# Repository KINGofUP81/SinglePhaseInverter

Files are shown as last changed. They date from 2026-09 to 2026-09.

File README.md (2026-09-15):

# Single-Phase H-Bridge Inverter

A **380 V DC → single-phase AC** full-bridge inverter power board designed in Altium Designer. It combines a 650 V MOSFET H-bridge, bootstrap gate drive, an LC output filter and a complete sensing suite (DC bus voltage and current, AC output voltage and current, heatsink temperature). Everything is broken out to header connectors for an external STM32 controller.

> Designed at **IIT Ropar** by **Afraaz Khan**, **Zeeshan** and **Kratika**, under the guidance of **Prof. Saifullah Payami**.

---

## Highlights

| | |
|---|---|
| ⚡ **DC bus** | 380 V input, 2 × 470 µF / 450 V bulk capacitors with bleeder resistors, film decoupling and snubbers |
| 🔀 **Power stage** | Full H-bridge of 4 × **STW69N65M5** 650 V MDmesh™ M5 MOSFETs (TO-247) on heatsinks |
| 🎛️ **Gate drive** | 2 × **IR2110** high/low-side drivers with MUR160G bootstrap diodes |
| 🌊 **Output filter** | 2.2 mH inductor + 3 × 2.2 µF film capacitors for a clean sinusoidal output |
| 📏 **Sensing** | DC current (ACS758), AC current (ZMCT103C CT), DC bus and AC output voltage dividers, LM35 temperature |
| 🛡️ **Protection** | MOV, TVS, Zener gate clamps, Schottky ADC clamps, shutdown/fault line |
| 🧱 **PCB** | 4-layer stack-up with separate power and signal grounds |

## System Overview

```
                  ┌───────────────────── H-bridge ─────────────────────┐
 +380 V DC ──┬──► │  Q1 ─┐                                   ┌─ Q2      │
             │    │      ├── NODE_A ──► L1 2.2 mH ──► C 3×2.2µF ──┼──► AC_LINE
  C5/C6 470µF│    │  Q3 ─┘                                   └─ Q4      │──► AC_NEUTRAL
             │    └──────▲────────────────────────────────────▲────────┘
            PGND     IR2110 (A)                           IR2110 (B)
                          ▲                                    ▲
                    HIN_A / LIN_A                        HIN_B / LIN_B
                          └──────────── STM32 controller ──────┘
                                           ▲
       VBUS_FB · CURRENT_FB · VOUT_FB · COUT_FB · TEMP_FB · SD_FAULT
```

An external STM32 generates sinusoidal PWM (e.g. SPWM) for the two legs. The IR2110s level-shift that PWM to drive the four MOSFETs, the LC filter recovers the fundamental, and the feedback signals close the voltage and current loops.

## Bill of Materials (key parts)

| Block | Part | Qty | Role |
|---|---|---|---|
| Power switches | STMicro **STW69N65M5** | 4 | 650 V N-channel MOSFETs, H-bridge |
| Gate drivers | Infineon **IR2110** | 2 | High- and low-side driver per leg |
| Bootstrap | MUR160G + 1 µF | 2 | Floating high-side supply |
| Gate network | 22 Ω, 1N4148W, BZT52C18, 1 kΩ | 4 each | Turn-on/off shaping, 18 V clamp, pull-down |
| DC link | ELG477M450AT6AA 470 µF / 450 V | 2 | Bulk bus capacitance |
| DC link | ECW-FE2J105QD 1 µF / 630 V film, ECW-FD2J333JB 33 nF film | 1 + 3 | High-frequency decoupling |
| Output filter | RLB0914-222KL 2.2 mH | 1 | Filter inductor |
| Output filter | ECW-FE2W225KA 2.2 µF film | 3 | Filter capacitors |
| DC current | Allegro **ACS758LCB-050B** | 1 | ±50 A isolated Hall-effect sensor |
| AC current | **ZMCT103C** + 49.9 Ω burden | 1 | Output current transformer |
| Voltage sense | PTF65 1 MΩ precision resistors | 7 | High-voltage dividers |
| Temperature | **LM35DZ** | 1 | Heatsink / board temperature |
| Regulator | LM7805 | 1 | 12 V → 5 V for sensors |
| Protection | B72220S0421K101 MOV, SMAJ15A TVS, BAT54C | 1 each | Surge, rail and ADC-input clamping |
| Noise | BLM21PG221SN1D ferrite bead | 1 | Couples power ground to signal ground |
| Connectors | KF301-2P screw terminals, Harwin M20 headers | 3 + 3 | Power I/O and controller interface |
| Thermal | Wakefield 694-50 heatsinks | 4 | MOSFET cooling |

The full BOM is in [`Singlephaseinverter/SinglephaseinverterBOM.xlsx`](Singlephaseinverter/SinglephaseinverterBOM.xlsx).

## Design Details

<details>
<summary><b>H-bridge & gate drive</b></summary>

Each leg (NODE_A, NODE_B) uses a high-side and a low-side STW69N65M5. With 650 V ratings they give comfortable margin on a 380 V bus, and their low R<sub>DS(on)</sub> keeps conduction loss down.

Each MOSFET gate has:
- a **22 Ω** series resistor to control dv/dt and damp ringing,
- a **1N4148W** diode across it for fast turn-off,
- an **18 V Zener** (BZT52C18) to clamp gate-source spikes,
- a **1 kΩ** gate-source pull-down that holds the device off while the driver is unpowered.

The IR2110s run from a 12 V rail. Their high-side outputs are powered by MUR160G ultrafast bootstrap diodes and local 1 µF capacitors, recharged whenever the low-side switch conducts. The shutdown inputs are tied to a filtered `SD_FAULT` line so the controller can disable all four gates at once.
</details>

<details>
<summary><b>DC link</b></summary>

Two 470 µF / 450 V electrolytics provide bulk energy storage, with a string of 1 MΩ resistors to bleed the bus down safely after power-off. A 1 µF / 630 V film capacitor and three 33 nF film capacitors sit close to the bridge to supply the high-frequency switching current that electrolytics can't.
</details>

<details>
<summary><b>Output LC filter</b></summary>

The switched bridge voltage passes through a 2.2 mH inductor into three parallel 2.2 µF film capacitors (6.6 µF total). This low-pass filter removes the PWM carrier and its harmonics, leaving the fundamental at `AC_LINE` / `AC_NEUTRAL`.
</details>

<details>
<summary><b>Sensing & feedback</b></summary>

| Signal | Sensor | Conditioning |
|---|---|---|
| `VBUS_FB` | 1 MΩ precision divider | Scales the 380 V bus into the ADC range |
| `CURRENT_FB` | ACS758LCB-050B | Isolated Hall-effect DC-link current, ±50 A |
| `VOUT_FB` | 1 MΩ precision divider | AC output voltage, biased with a 10 kΩ network |
| `COUT_FB` | ZMCT103C CT | 49.9 Ω burden, 10 kΩ / 10 kΩ mid-rail bias |
| `TEMP_FB` | LM35DZ | 10 mV/°C analog output |

A BAT54C dual Schottky provides input clamping to protect the MCU's ADC pins, and small filter capacitors on the feedback paths reduce switching noise.
</details>

<details>
<summary><b>Protection</b></summary>

- **MOV** (420 V<sub>RMS</sub>) absorbs surge energy.
- **SMAJ15A TVS** protects the 12 V auxiliary rail.
- **Zener gate clamps** protect each MOSFET gate.
- **Schottky clamps** protect the ADC inputs.
- **`SD_FAULT`** gives the controller a hardware path to shut down all four gates.
</details>

<details>
<summary><b>PCB layout</b></summary>

4-layer FR-4 stack-up:

| Layer | Name | Use |
|---|---|---|
| L1 | `POWER` | High-current bus and bridge routing |
| L2 | `PGND` | Power ground plane |
| L3 | `LOW_POWER` | Gate drive and auxiliary supplies |
| L4 | `SIGNAL/SGND` | Sensing, controller interface, signal ground |

- **Zoning:** the high-voltage section (bus capacitors, bridge, heatsinks, output filter) is kept physically apart from the low-voltage sensing and controller interface.
- **Grounds:** the power and signal grounds are separate, joined through a ferrite bead.
- **Iterations:** the design went through several layout revisions (`PCB1` → `PCB2 (ITERATION)` → `PCBFINAL`), with DRC reports and Gerber/ODB++ outputs generated for each.
</details>

## Controller Interface

| Header | Pins | Signals |
|---|---|---|
| **P1** (4-pin) | 1–4 | `HIN_A`, `LIN_A`, `HIN_B`, `LIN_B` (PWM inputs) |
| **P5** (2-pin) | 1–2 | `CURRENT_FB`, `VBUS_FB` |
| **P6** (6-pin) | 1–6 | `SD_FAULT`, `TEMP_FB`, `SGND`, `COUT_FB`, `VOUT_FB`, `3.3V` |

| Terminal | Connection |
|---|---|
| **P3** | +380 V DC bus input / PGND |
| **P2** | AC output (`AC_LINE` / `AC_NEUTRAL`) |
| **P4** | +12 V auxiliary supply / PGND |

## Repository Contents

```
Singlephaseinverter/
├── Singlephaseinverter.PrjPcb        # Altium project (open this)
├── Sheet2.SchDoc                     # Main schematic
├── PCBFINAL.PcbDoc                   # Final PCB layout
├── PCB1.PcbDoc, PCB2(ITERATION).PcbDoc  # Earlier layout iterations
├── Schlib2.SchLib, PcbLib2.PcbLib    # Project libraries
├── <part folders>/                   # Vendor symbols & footprints (SchLib/PcbLib)
├── *.stp / *.step                    # 3D models
├── SinglephaseinverterBOM.xlsx       # Bill of materials
├── Inverter(FINAL SCHEM).pdf         # Schematic + PCB prints
├── Singlephaseinverter(*).pdf        # Review / submission prints
└── Project Outputs for Singlephaseinverter/
    ├── PCBFINAL.G*                   # Gerbers + drill
    ├── odb/                          # ODB++ fabrication data
    └── Design Rule Check - *.html    # DRC reports
```

📄 **Start here:** [`Inverter(FINAL SCHEM).pdf`](Singlephaseinverter/Inverter(FINAL%20SCHEM).pdf) has the full schematic and PCB layout without needing Altium.

## Getting Started

1. Open `Singlephaseinverter/Singlephaseinverter.PrjPcb` in **Altium Designer**.
2. Review `PCBFINAL.PcbDoc` and re-run DRC.
3. Fabrication files (Gerber, drill, ODB++) are in `Project Outputs for Singlephaseinverter/`.

> ⚠️ **High voltage.** This board runs from a 380 V DC bus and its bulk capacitors store lethal energy. Bring it up with an isolated, current-limited supply, confirm the bus has bled down before touching it, and always use proper isolation and PPE.

## Roadmap

- [ ] Assemble and bring up the power stage
- [ ] Closed-loop SPWM control on STM32 (voltage and current loops)
- [ ] Dead-time and switching-loss optimisation
- [ ] THD measurement of the filtered output
- [ ] Thermal characterisation under load

## Team

| Name | Role |
|---|---|
| **Afraaz Khan** | Hardware design |
| **Zeeshan** | Hardware design |
| **Kratika** | Hardware design |
| **Prof. Saifullah Payami** | Faculty guide, IIT Ropar |

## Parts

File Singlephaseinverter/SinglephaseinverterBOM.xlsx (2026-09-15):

Name | Description | Designator | Footprint | LibRef | Quantity
22u | EEU-FR1H220 | C1, C7 | 22uF | 22u | 2
1uF(New) | CL21B105MBFNNNE | C2, C9 | 1uF(New) | 1uF(New) | 2
1uF | C1206C105K1RACTU | C3, C8, C18 | 1uF | 1uF | 3
1uF Film | ECW-FE2J105QD | C4 | 1.0uF/630V | 1uF Film | 1
470uF/450V | ELG477M450AT6AA | C5, C6 | 470 µF/450 V | 470uF/450V | 2
33nF | ECW-FD2J333JB | C10, C11, C12 | 33nF | 33nF | 3
1nF | C315C102KAG5TA | C13, C14, C20 | 1nF | 1nF | 3
2.2uF | ECWFE2W225KA | C15, C16, C17 | 2.2uF | 2.2uF | 3
100nF/100V | C1210C104K1RACAUTO | C19, C21, C22, R28 | 100nF/100V | 100nF/100V | 4
Rectifier | MUR160G | D1, D2 | Rectifier | Rectifier | 2
Fast Switching Diode | 1N4148W-7-F | D3, D6, D9, D10 | Fast Switching Diode | Fast Switching Diode | 4
Zener Diode | BZT52C18 | D4, D5, D7, D8 | Zener Diode | Zener Diode | 4
Dual Diode | BAT54C | D11 | Dual Diode | Dual Diode | 1
Ferrite Bead | BLM21PG221SN1D | F1 | Ferrite Bead | Ferrite Bead | 1
Gate driver | IR2110 | G1, G2 | Gate Driver | Gate driver | 2
Heatsink | 694-50 | H1, H2, H3, H4 | Heatsink | Heatsink | 4
2.2mH | RLB0914-222KL | L1 | 2.2mH | 2.2mH | 1
4 PIN STM | M20-9990446 | P1 | 4 PIN STM | 4 PIN STM | 1
2 Pin Connector | KF301-2P | P2, P3, P4 | 2 Pin Connector | 2 Pin Connector | 3
2 PIN STM | M20-9990246 | P5 | 2 PIN STM | 2 PIN STM | 1
6 PIN STM | M20-9990646 | P6 | 6 PIN STM | 6 PIN STM | 1
Mosfet | STW69N65M5 | Q1, Q2, Q3, Q4 | Mosfet | Mosfet | 4
12 TO 5 | LM7805S | Q5 | 12 TO 5 | 12 TO 5 | 1
1M | PTF651M0000BYEA | R3, R9, R15, R16, R19, R21, R22 | 1M | 1M | 7
100 | CFR-25JB-52-100R | R4, R12 | 100 | 100 | 2
22 | CFR-25JR-52-22R | R5, R6, R10, R11 | 22 | 22 | 4
1K | MF0207FRE52-1K | R7, R8, R14, R18, R20, R29 | 1K | 1K | 6
10k | RC1206FR-0710KL | R13, R17, R23, R24, R25, R26, R27, R31, R32, R33 | 10K | 10k | 10
50 | MF0207FTE52-49R9 | R30 | 50 | 50 | 1
TVS | SMAJ15A | T1 | TVS | TVS | 1
Current Transform | ZMCT103C | T2 | Current Transformer | Current Transform | 1
Temp Sensor | LM35DZ | T6 | Temp Sensor | Temp Sensor | 1
MOV | B72220S0421K101 | V1 | MOV | MOV | 1
Current sensor | ACS758LCB-050B-PFF-T | W1 | Current Sensor | Current sensor | 1

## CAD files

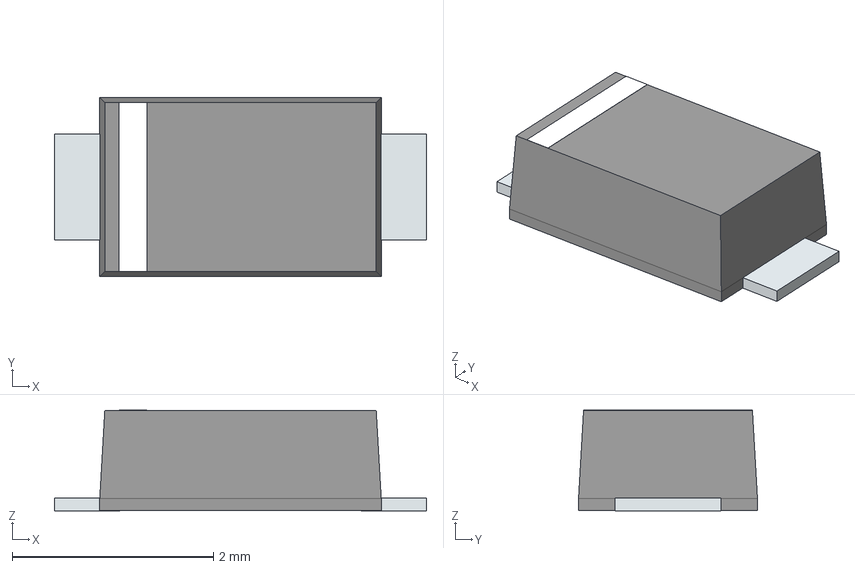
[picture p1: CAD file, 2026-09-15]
Singlephaseinverter/1N4148W-7-F.stp
3.70 x 1.78 x 1.00 mm
PinKIdent
PinK
PinA

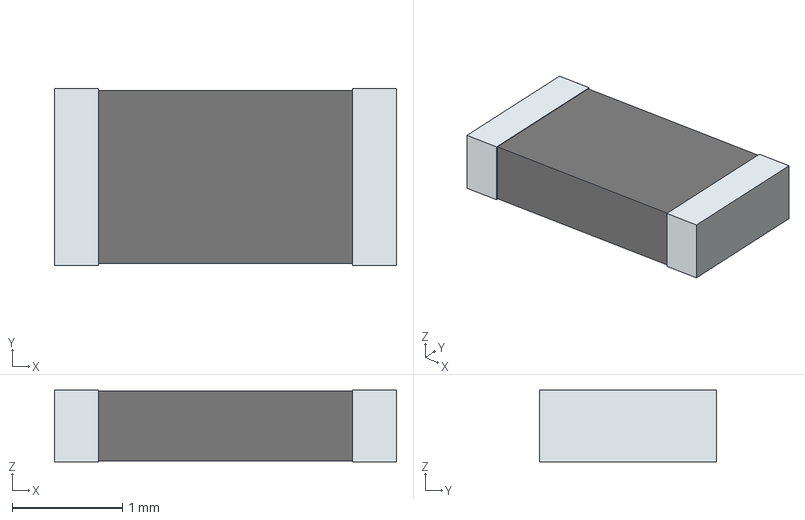
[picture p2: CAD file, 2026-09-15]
Singlephaseinverter/RC1206FR-07330KL.stp
3.10 x 1.60 x 0.65 mm
term1
term2

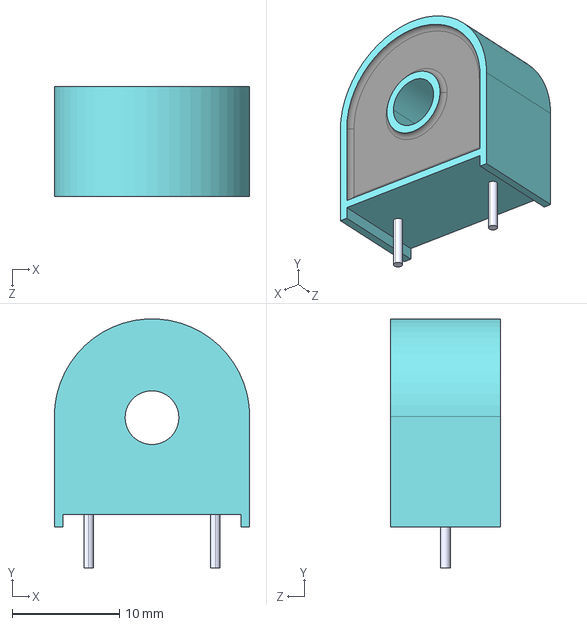
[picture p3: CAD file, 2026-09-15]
Singlephaseinverter/ZMCT103C--3DModel-STEP-510211.STEP
18.2 x 23.2 x 10.2 mm

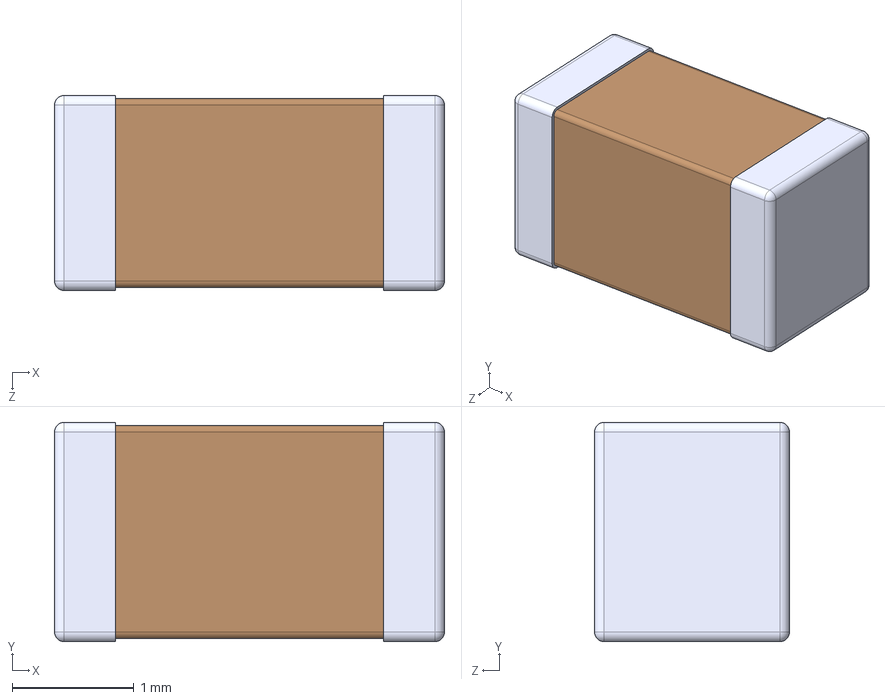
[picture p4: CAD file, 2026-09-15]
Singlephaseinverter/C1206C105K1RACTU.STEP
3.20 x 1.80 x 1.60 mm

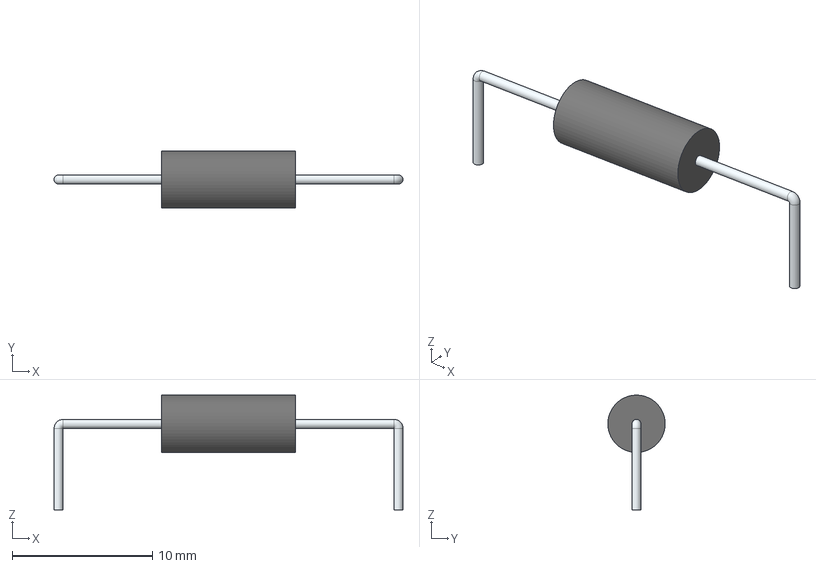
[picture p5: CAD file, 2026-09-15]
Singlephaseinverter/PTF651M0000BYEA.stp
24.9 x 4.09 x 8.18 mm
SimpleBody

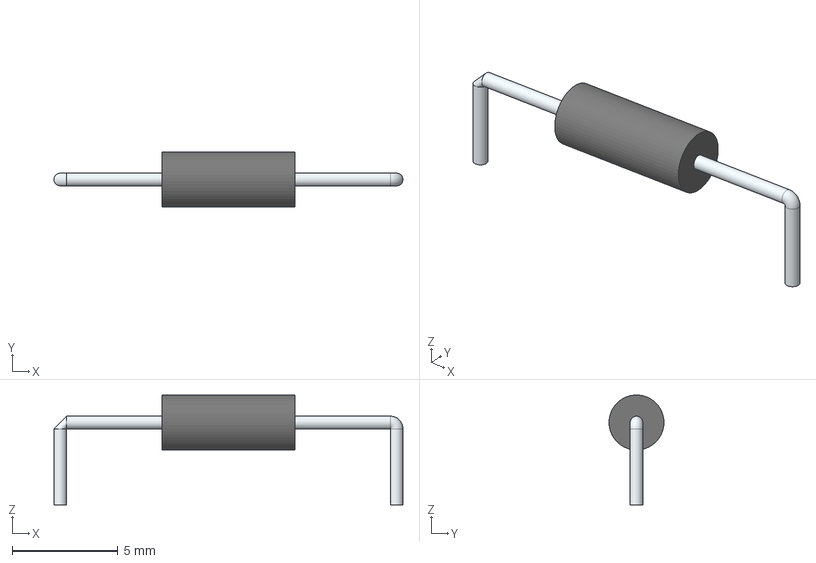
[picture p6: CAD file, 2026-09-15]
Singlephaseinverter/MF0207FRE52-1K.stp
16.5 x 2.60 x 5.20 mm
SimpleBody

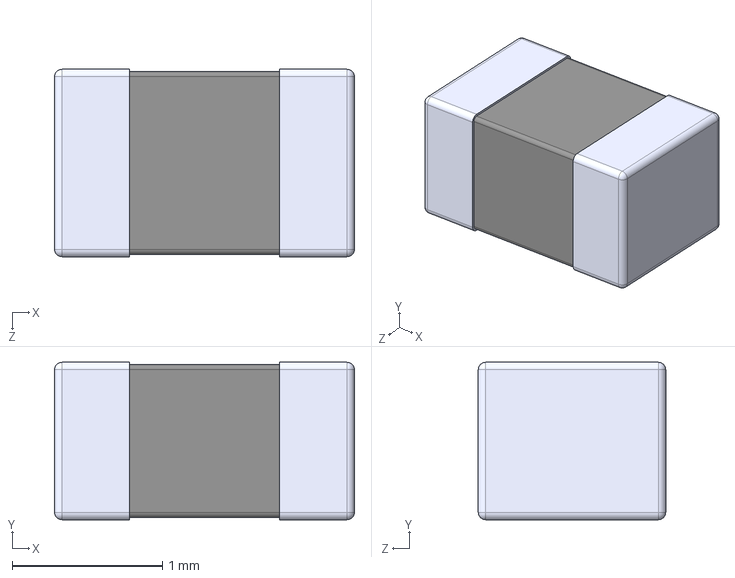
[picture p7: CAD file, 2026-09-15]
Singlephaseinverter/BLM21PG221SN1D.STEP
2.00 x 1.05 x 1.25 mm

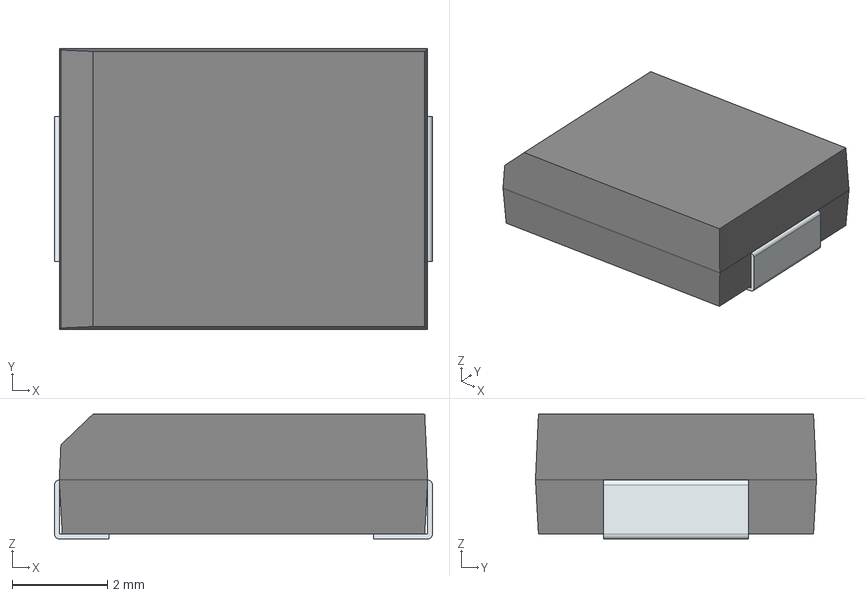
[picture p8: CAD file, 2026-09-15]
Singlephaseinverter/SMCJ440A.stp
7.94 x 5.91 x 2.62 mm
FilletPin1
FilletPin2

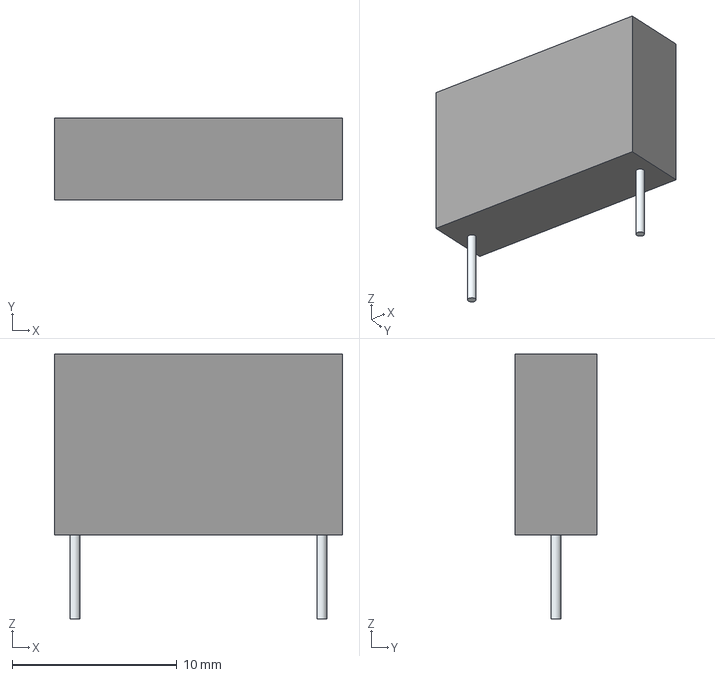
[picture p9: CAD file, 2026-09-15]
Singlephaseinverter/ECW-FE2J104JA.stp
17.5 x 5.00 x 16.1 mm
Leads

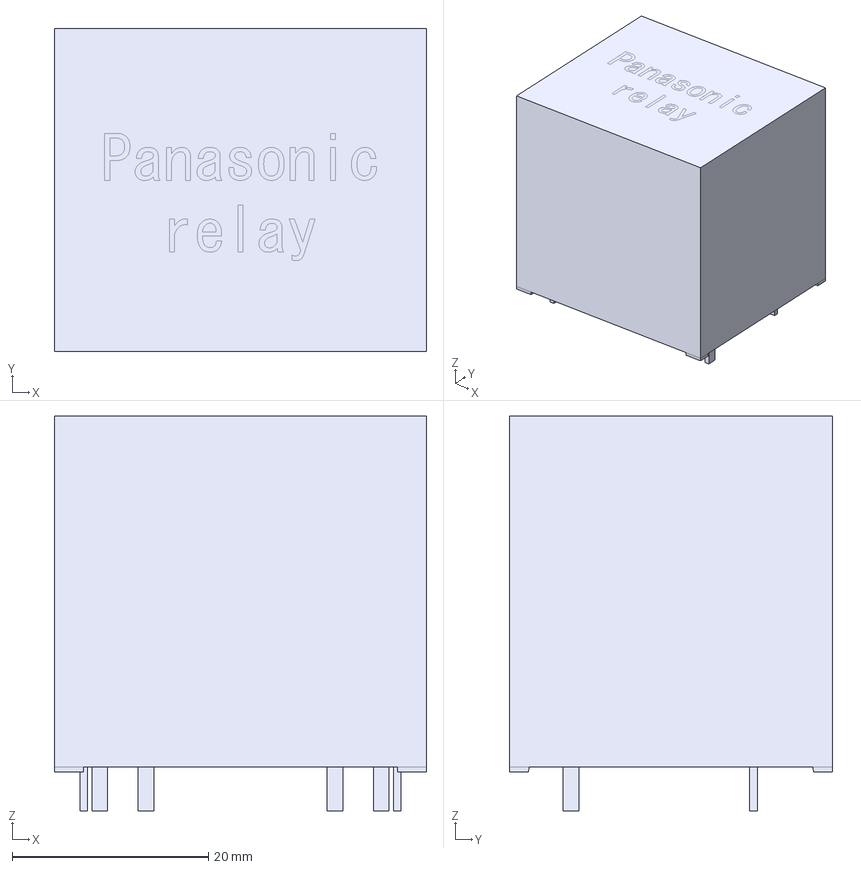
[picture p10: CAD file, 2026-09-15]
Singlephaseinverter/HE1aN-P-DC12V.stp
38.0 x 33.0 x 40.3 mm

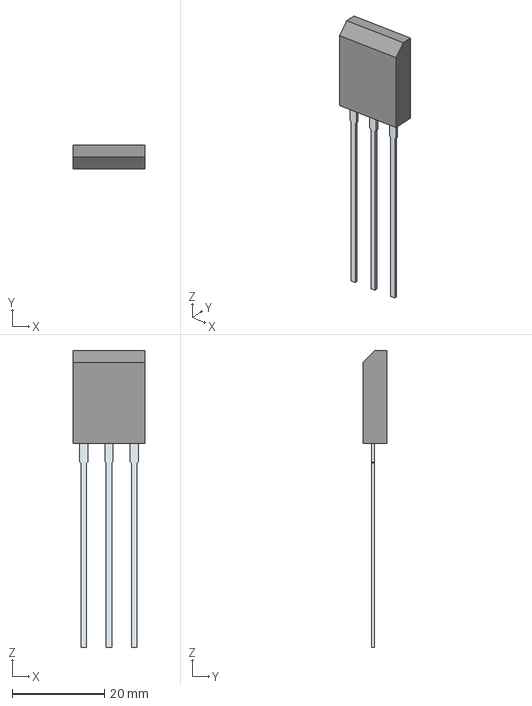
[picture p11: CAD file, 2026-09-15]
Singlephaseinverter/STW69N65M5.stp
15.6 x 5.15 x 64.5 mm
PinsArray

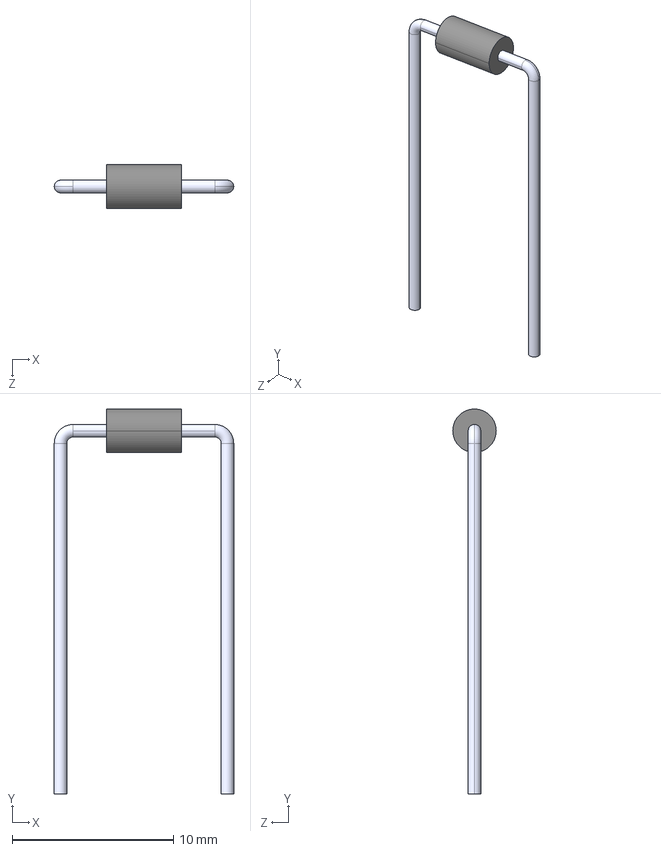
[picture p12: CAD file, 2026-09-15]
Singlephaseinverter/MUR160G.STEP
11.1 x 23.9 x 2.70 mm

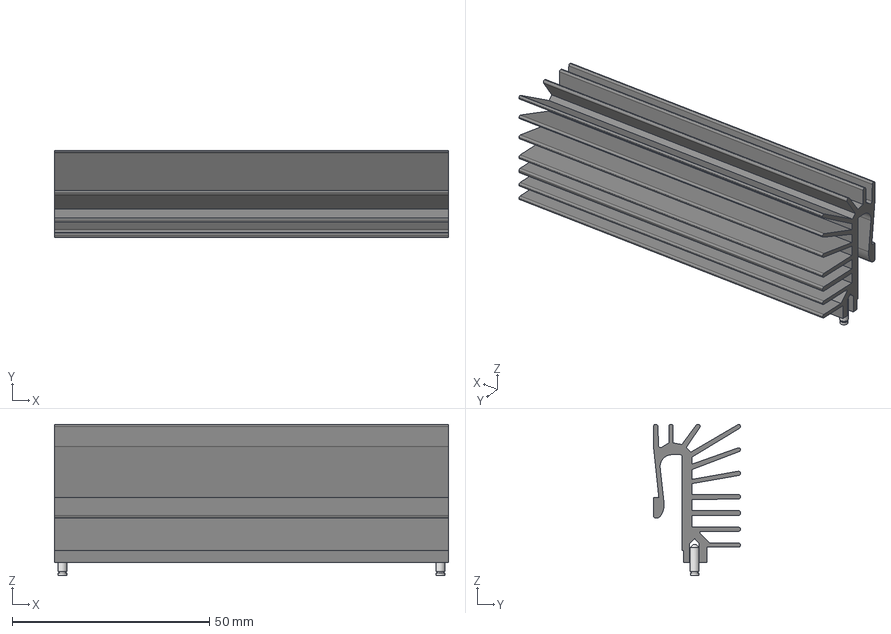
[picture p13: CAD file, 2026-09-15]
Singlephaseinverter/694-50(NuNew).step
100.0 x 22.1 x 38.4 mm

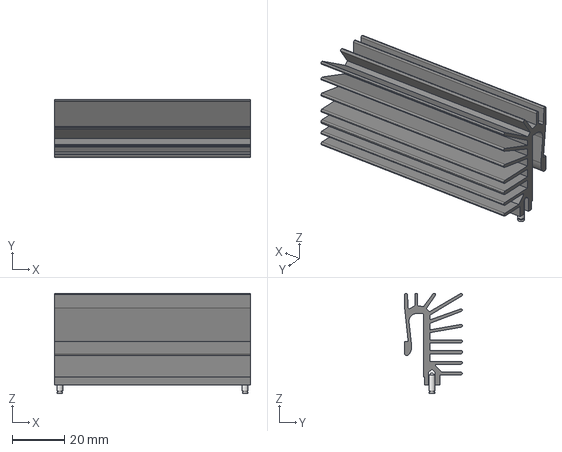
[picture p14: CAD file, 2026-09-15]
Singlephaseinverter/694-50(New).step
75.0 x 22.1 x 38.4 mm

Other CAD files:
Singlephaseinverter/RC1206FR-0710KL.stp
Singlephaseinverter/ECW-FD2J333JB.STEP
Singlephaseinverter/ELG477M450AT6AA.stp
Singlephaseinverter/TSW-114-07-G-S.stp
Singlephaseinverter/0451001.MRL.stp
Singlephaseinverter/1140-681K-RC.stp
Singlephaseinverter/694-50.stp
Singlephaseinverter/694-75.stp
Singlephaseinverter/ATDR5.stp
Singlephaseinverter/B72220S0421K101.stp
Singlephaseinverter/CFR-25JR-52-22R.stp
Singlephaseinverter/ECW-FE2J104K.STEP
Singlephaseinverter/ECW-FE2J105Q5.stp
Singlephaseinverter/ECW-FE2J105QD.stp
Singlephaseinverter/ECW-FE2W225KA.STEP
Singlephaseinverter/GRM32ER71H106KA12L.STEP
Singlephaseinverter/RLB0914-222KL.stp

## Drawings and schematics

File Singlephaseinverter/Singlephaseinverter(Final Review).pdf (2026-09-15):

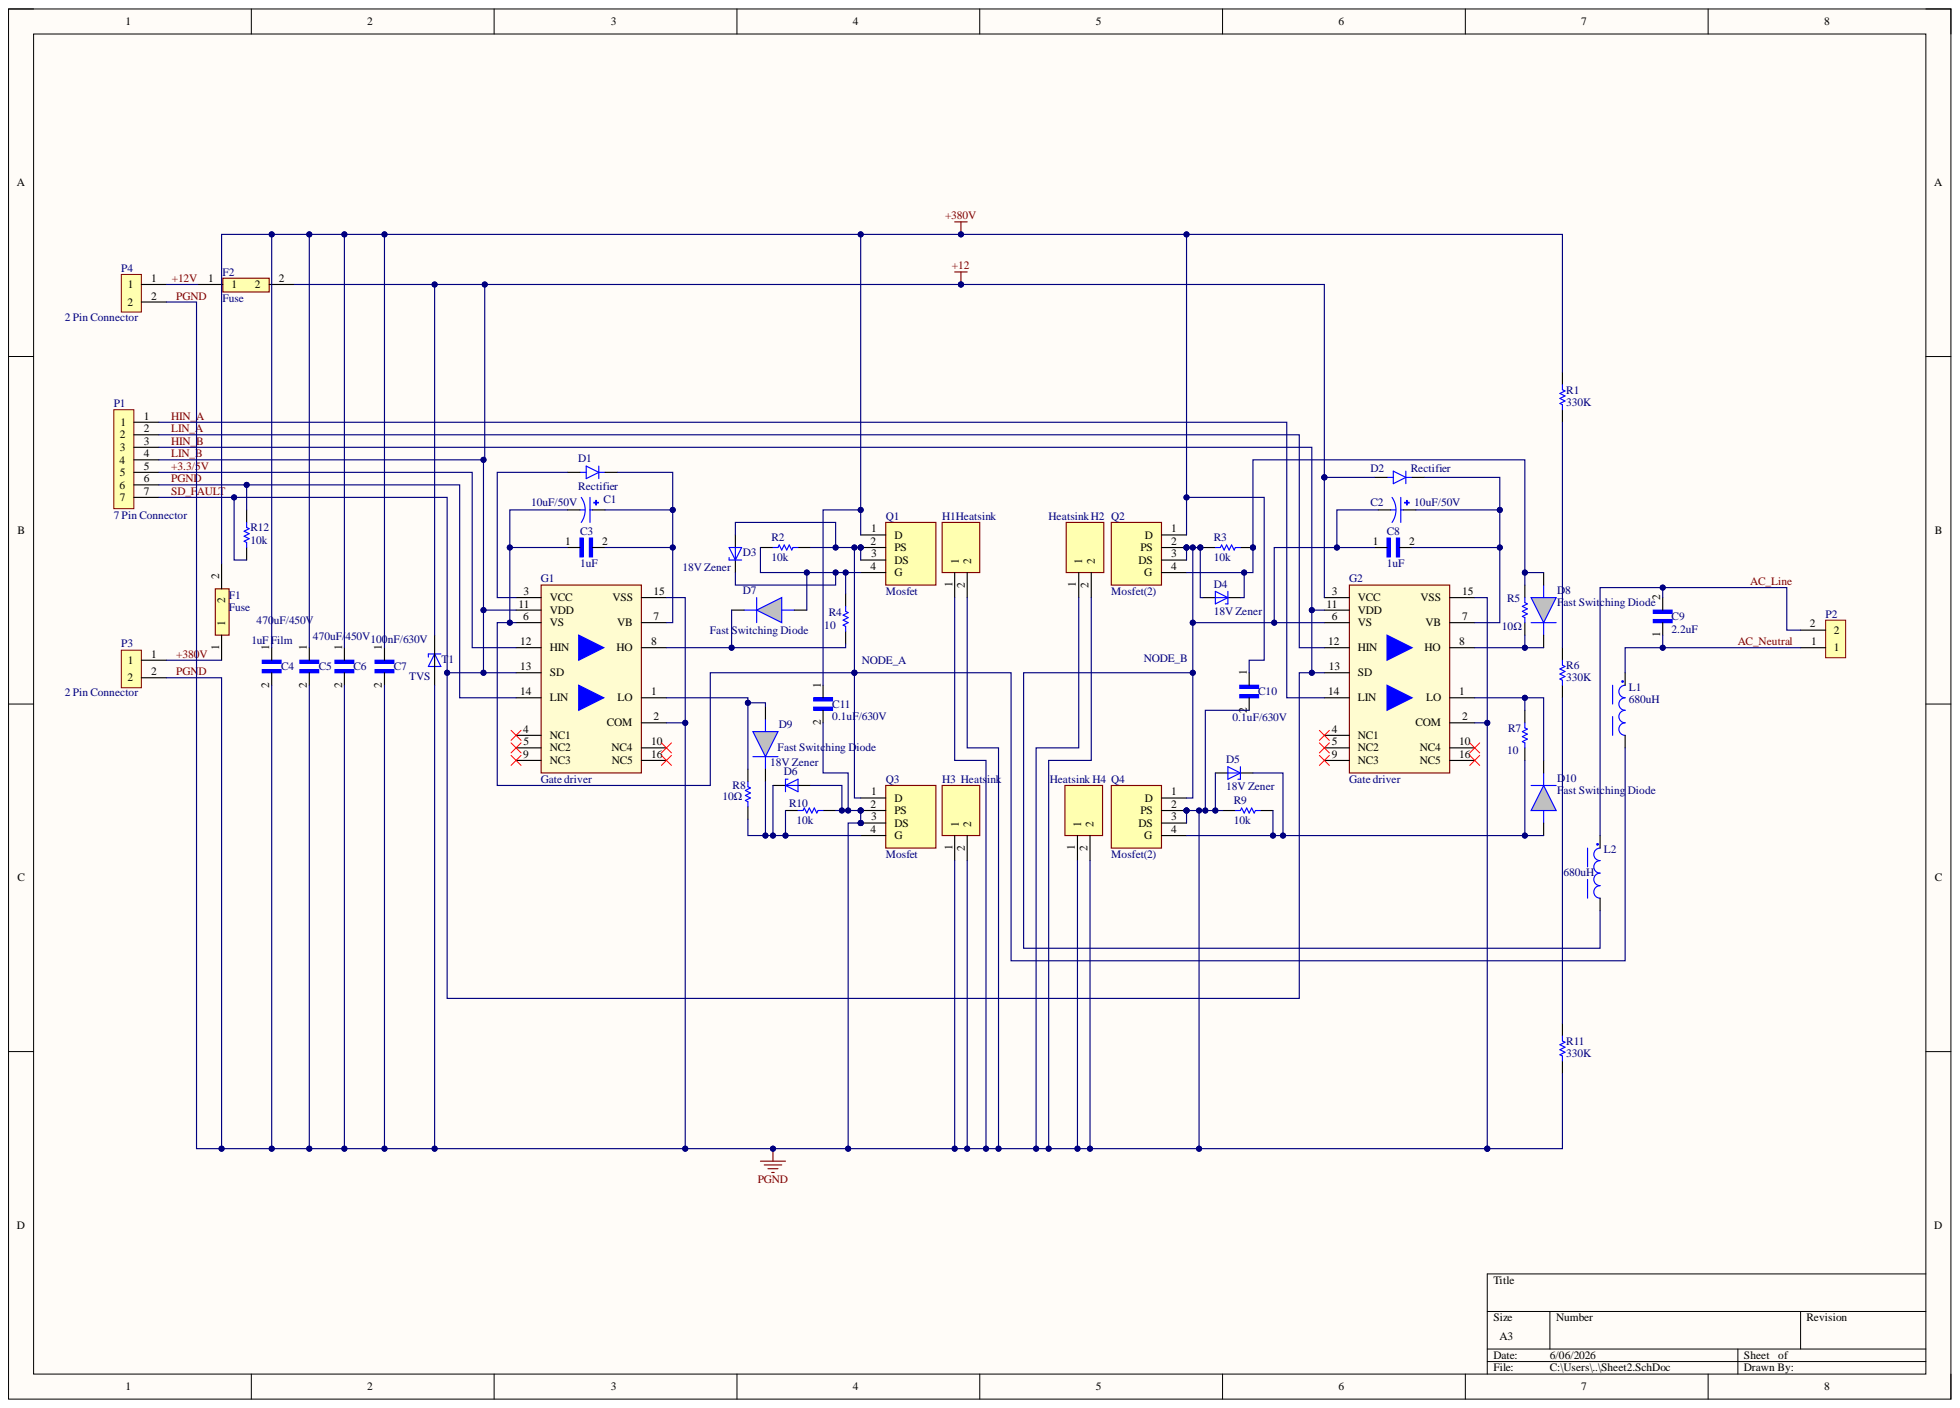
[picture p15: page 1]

Connector HIN_A LIN_A HIN_B LIN_B +3.3/5V 4 | Q H 1

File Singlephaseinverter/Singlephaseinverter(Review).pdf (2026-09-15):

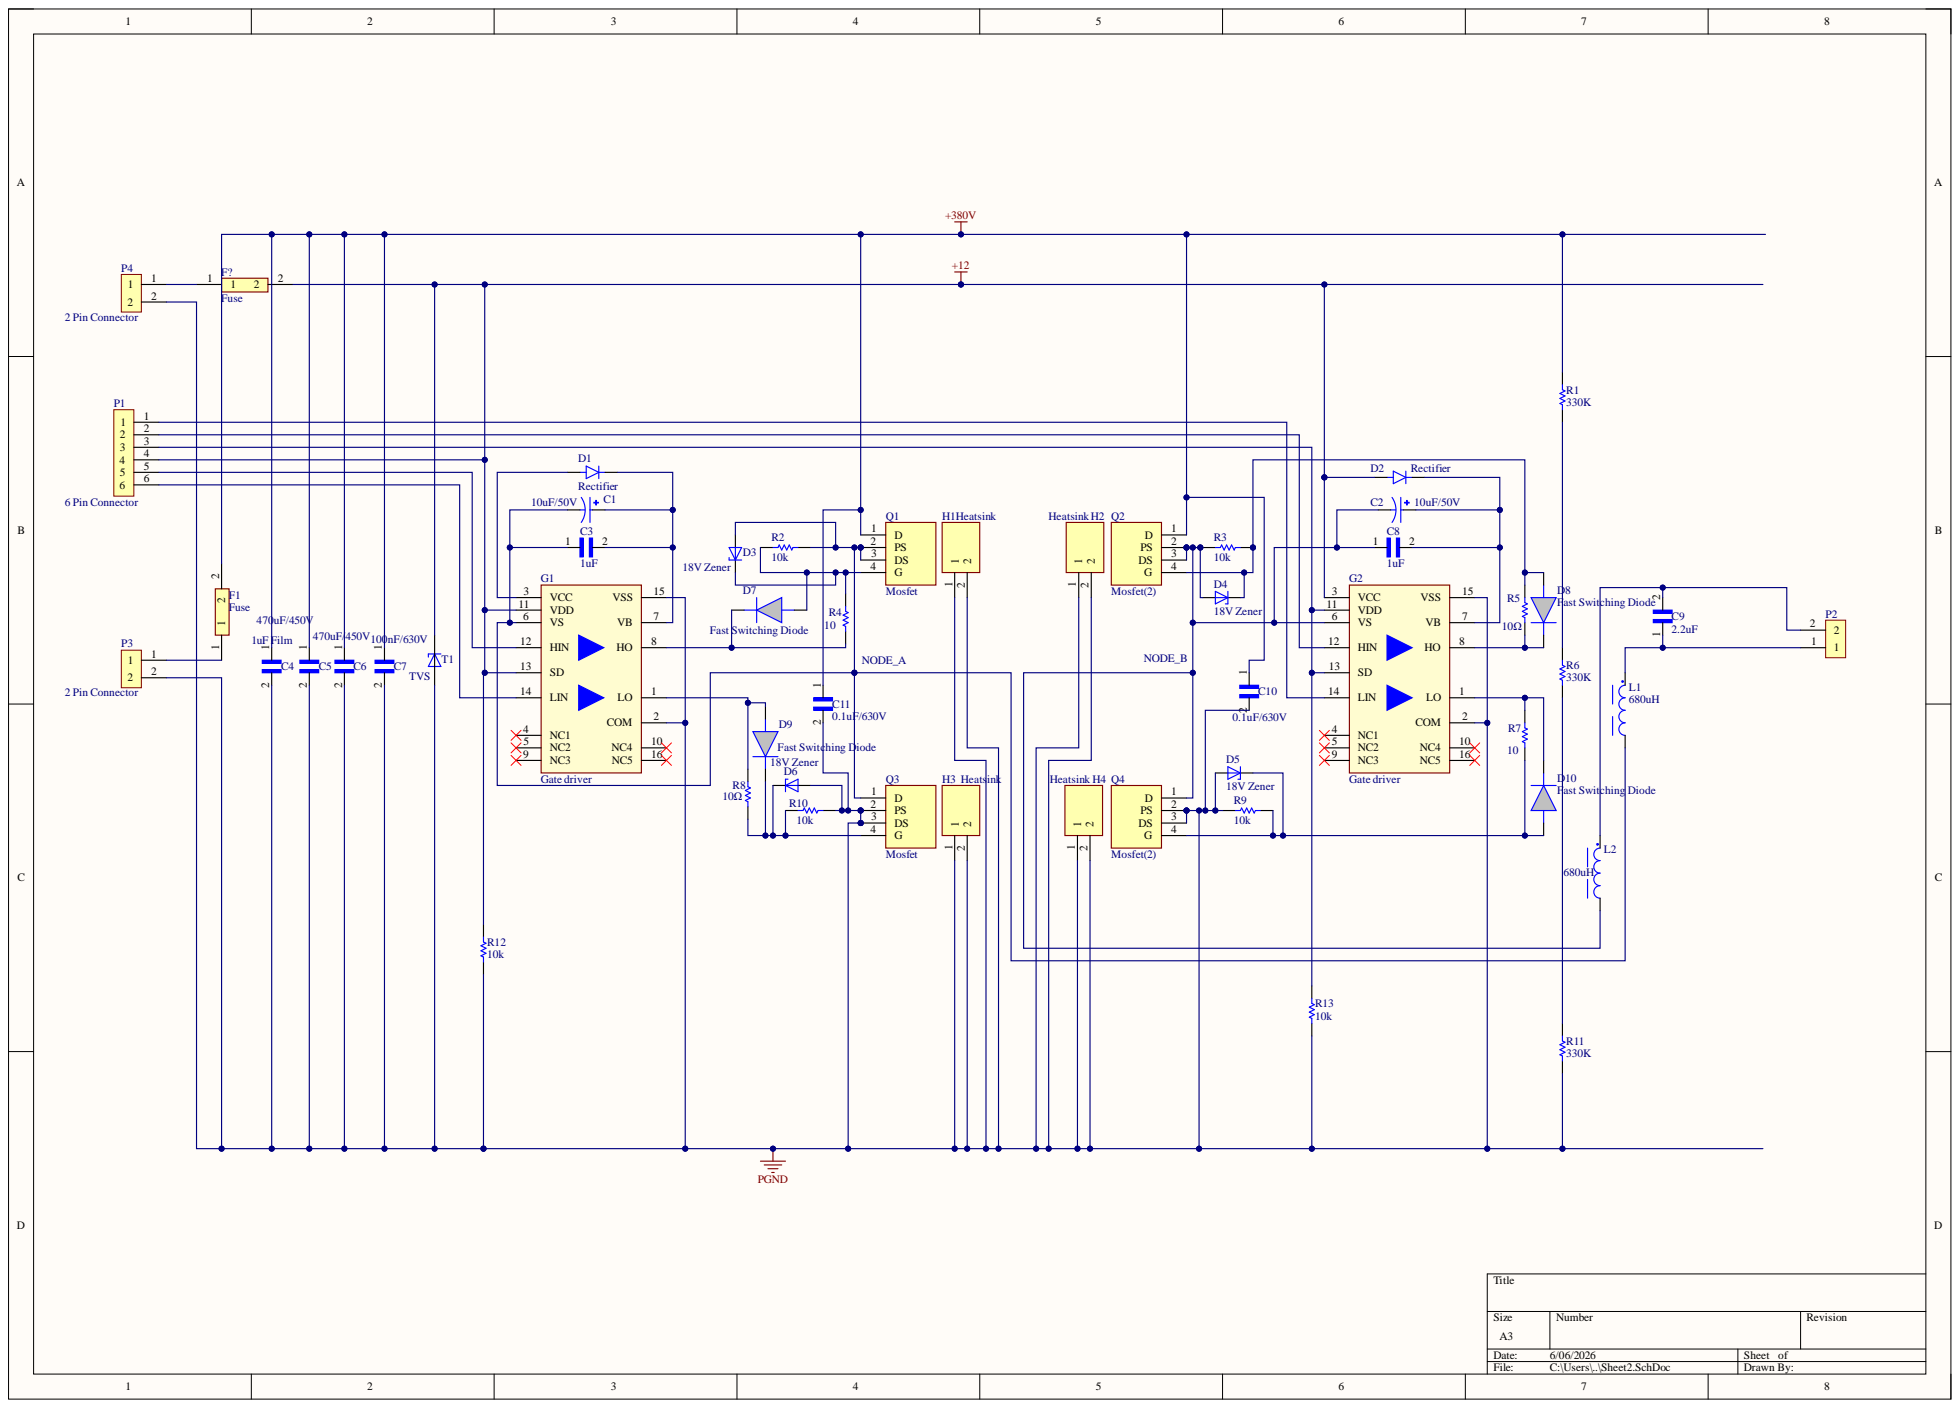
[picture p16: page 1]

4 | Q H 1 Heat s i nk Heat s i nk H 2 Q
6 | | fi er

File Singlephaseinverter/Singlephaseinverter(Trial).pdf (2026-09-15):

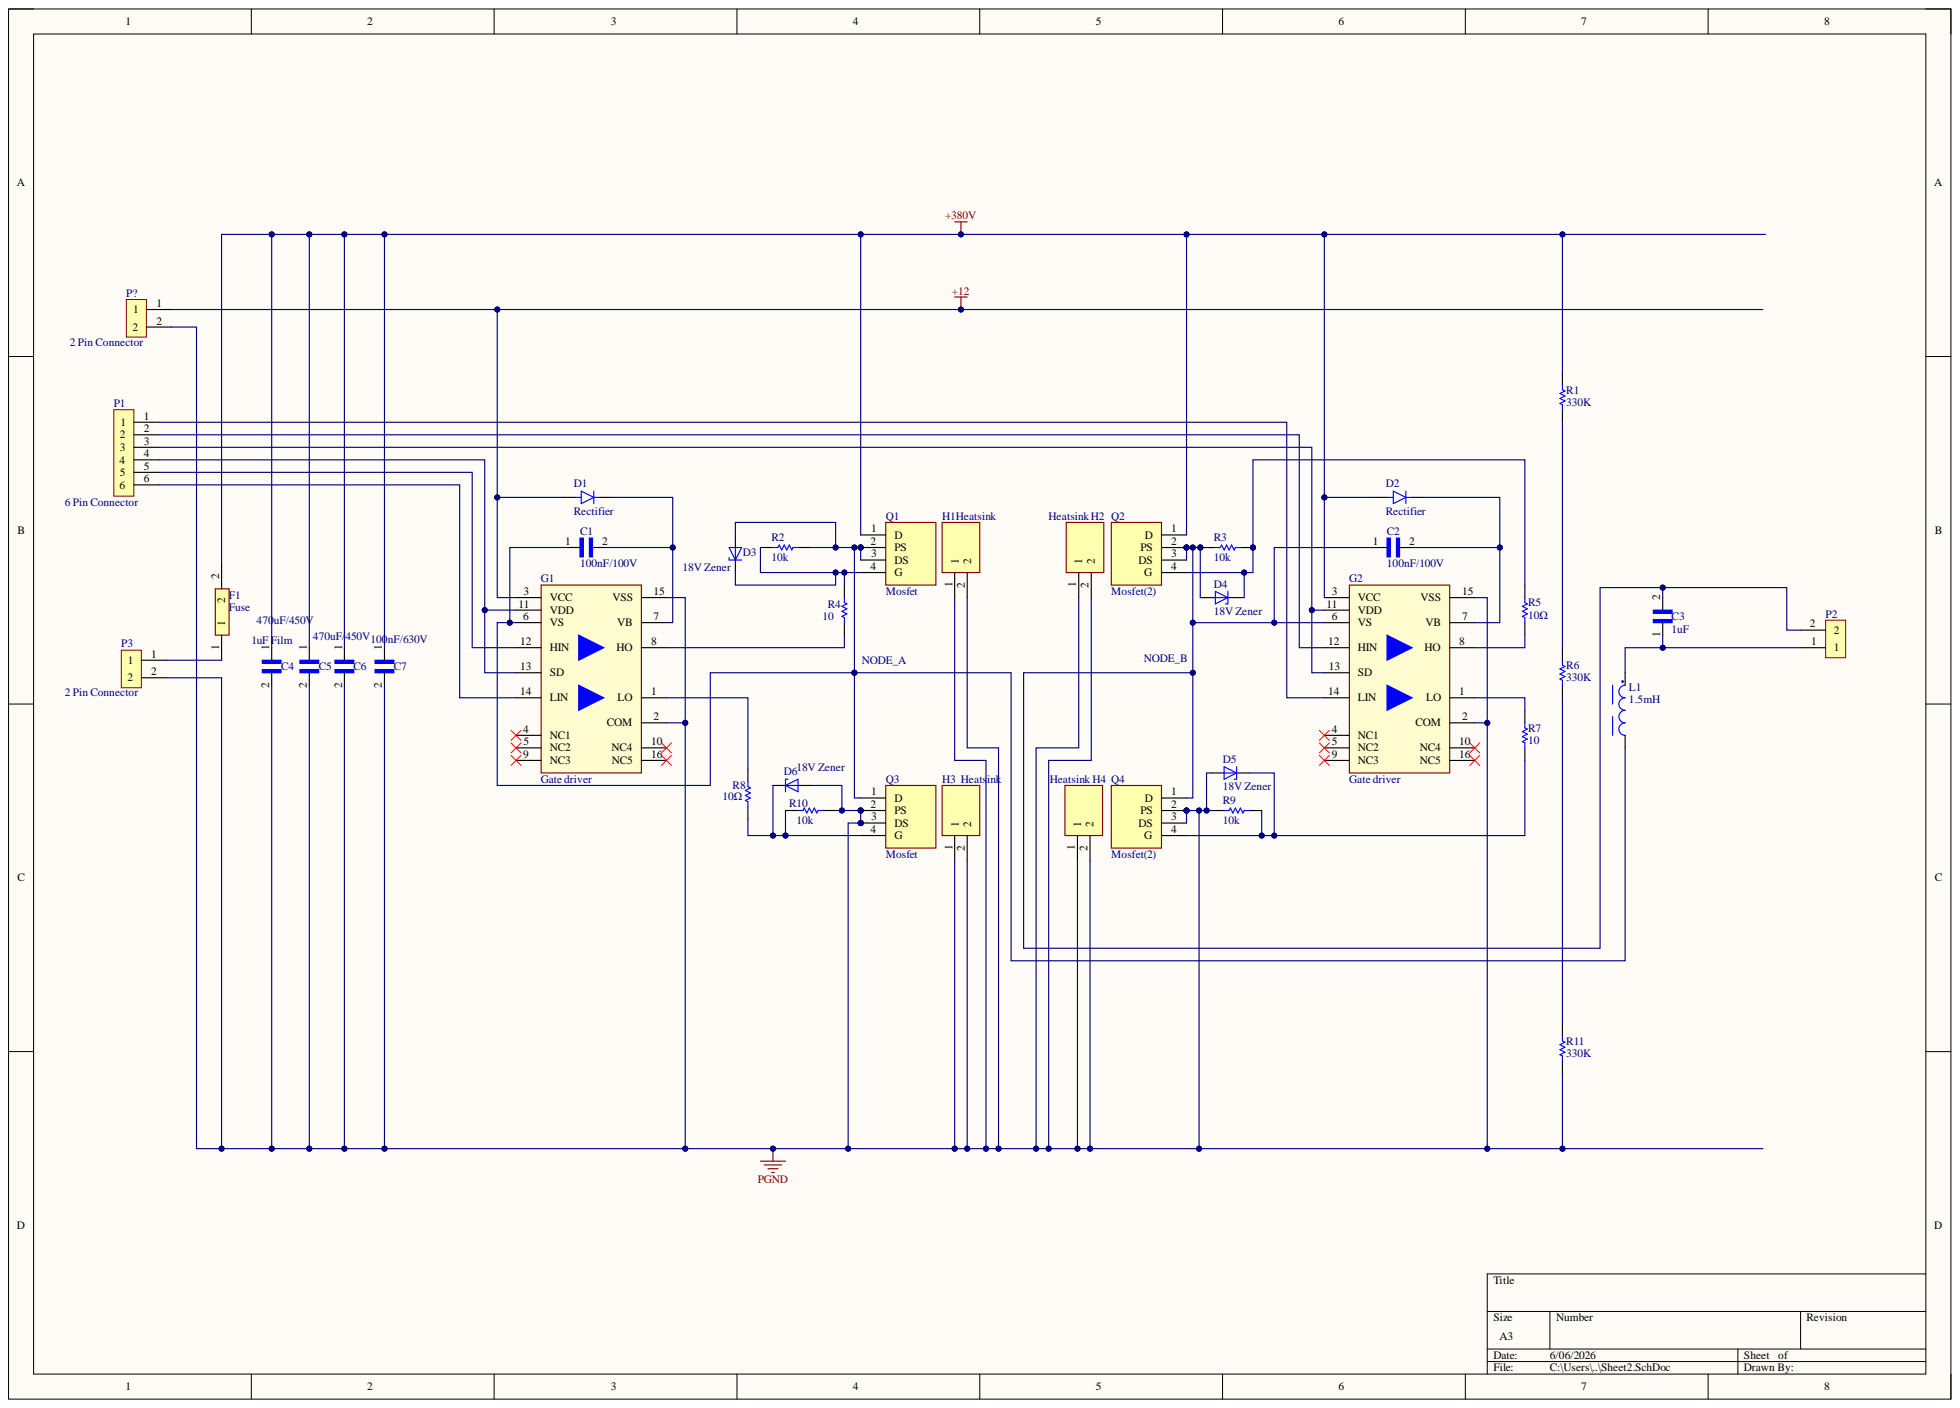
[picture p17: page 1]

4 | Q H 1 Heat s s i nk H 2 Q

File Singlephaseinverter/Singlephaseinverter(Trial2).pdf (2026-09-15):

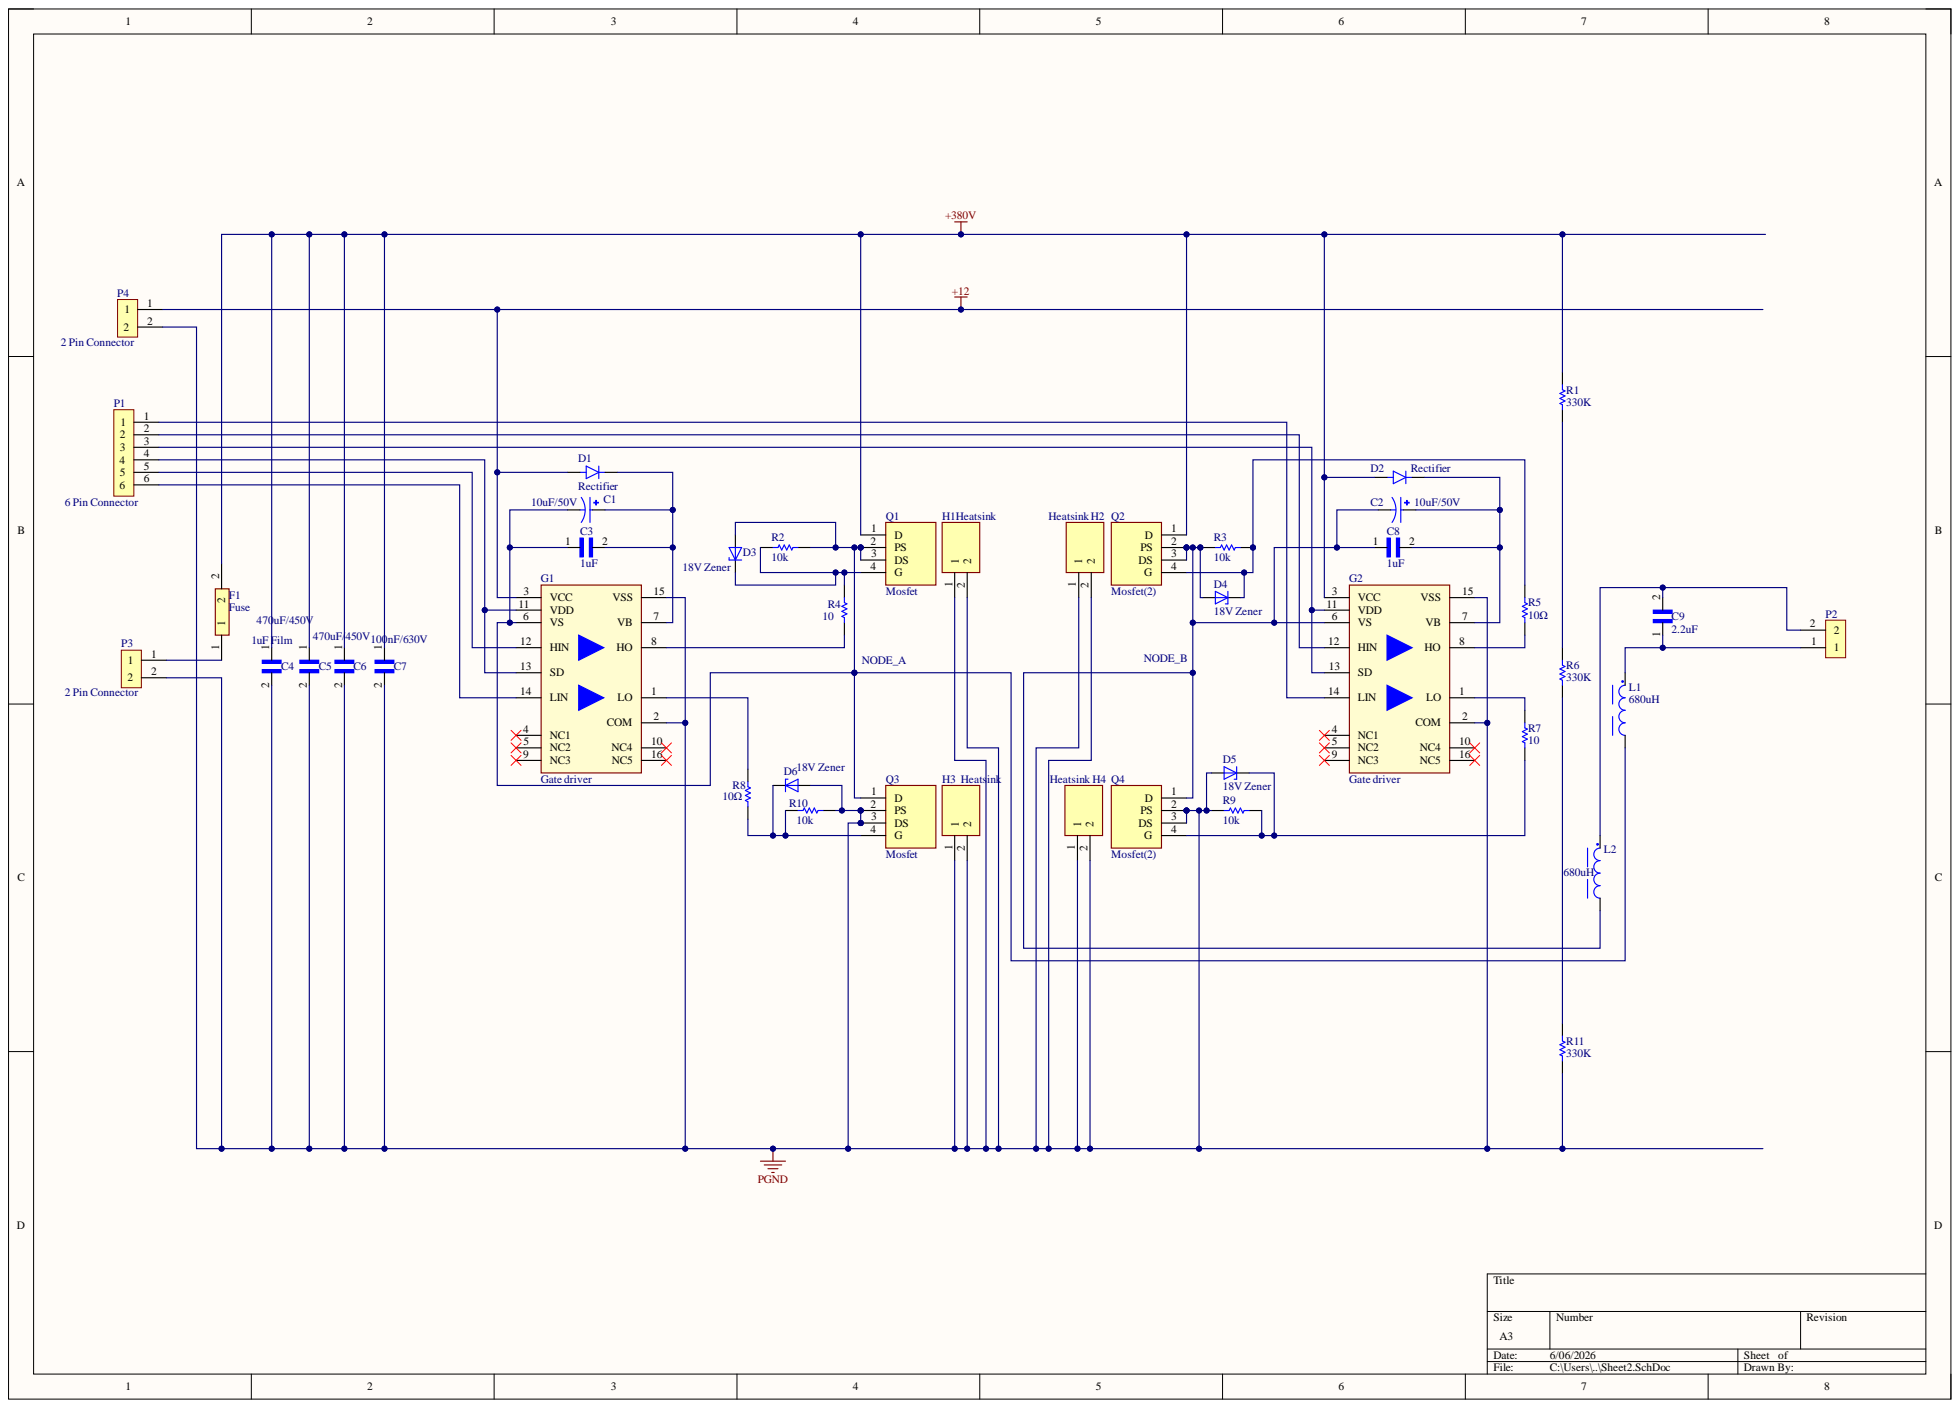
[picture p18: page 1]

4 | Q H 1 Heat s s i nk H 2 Q

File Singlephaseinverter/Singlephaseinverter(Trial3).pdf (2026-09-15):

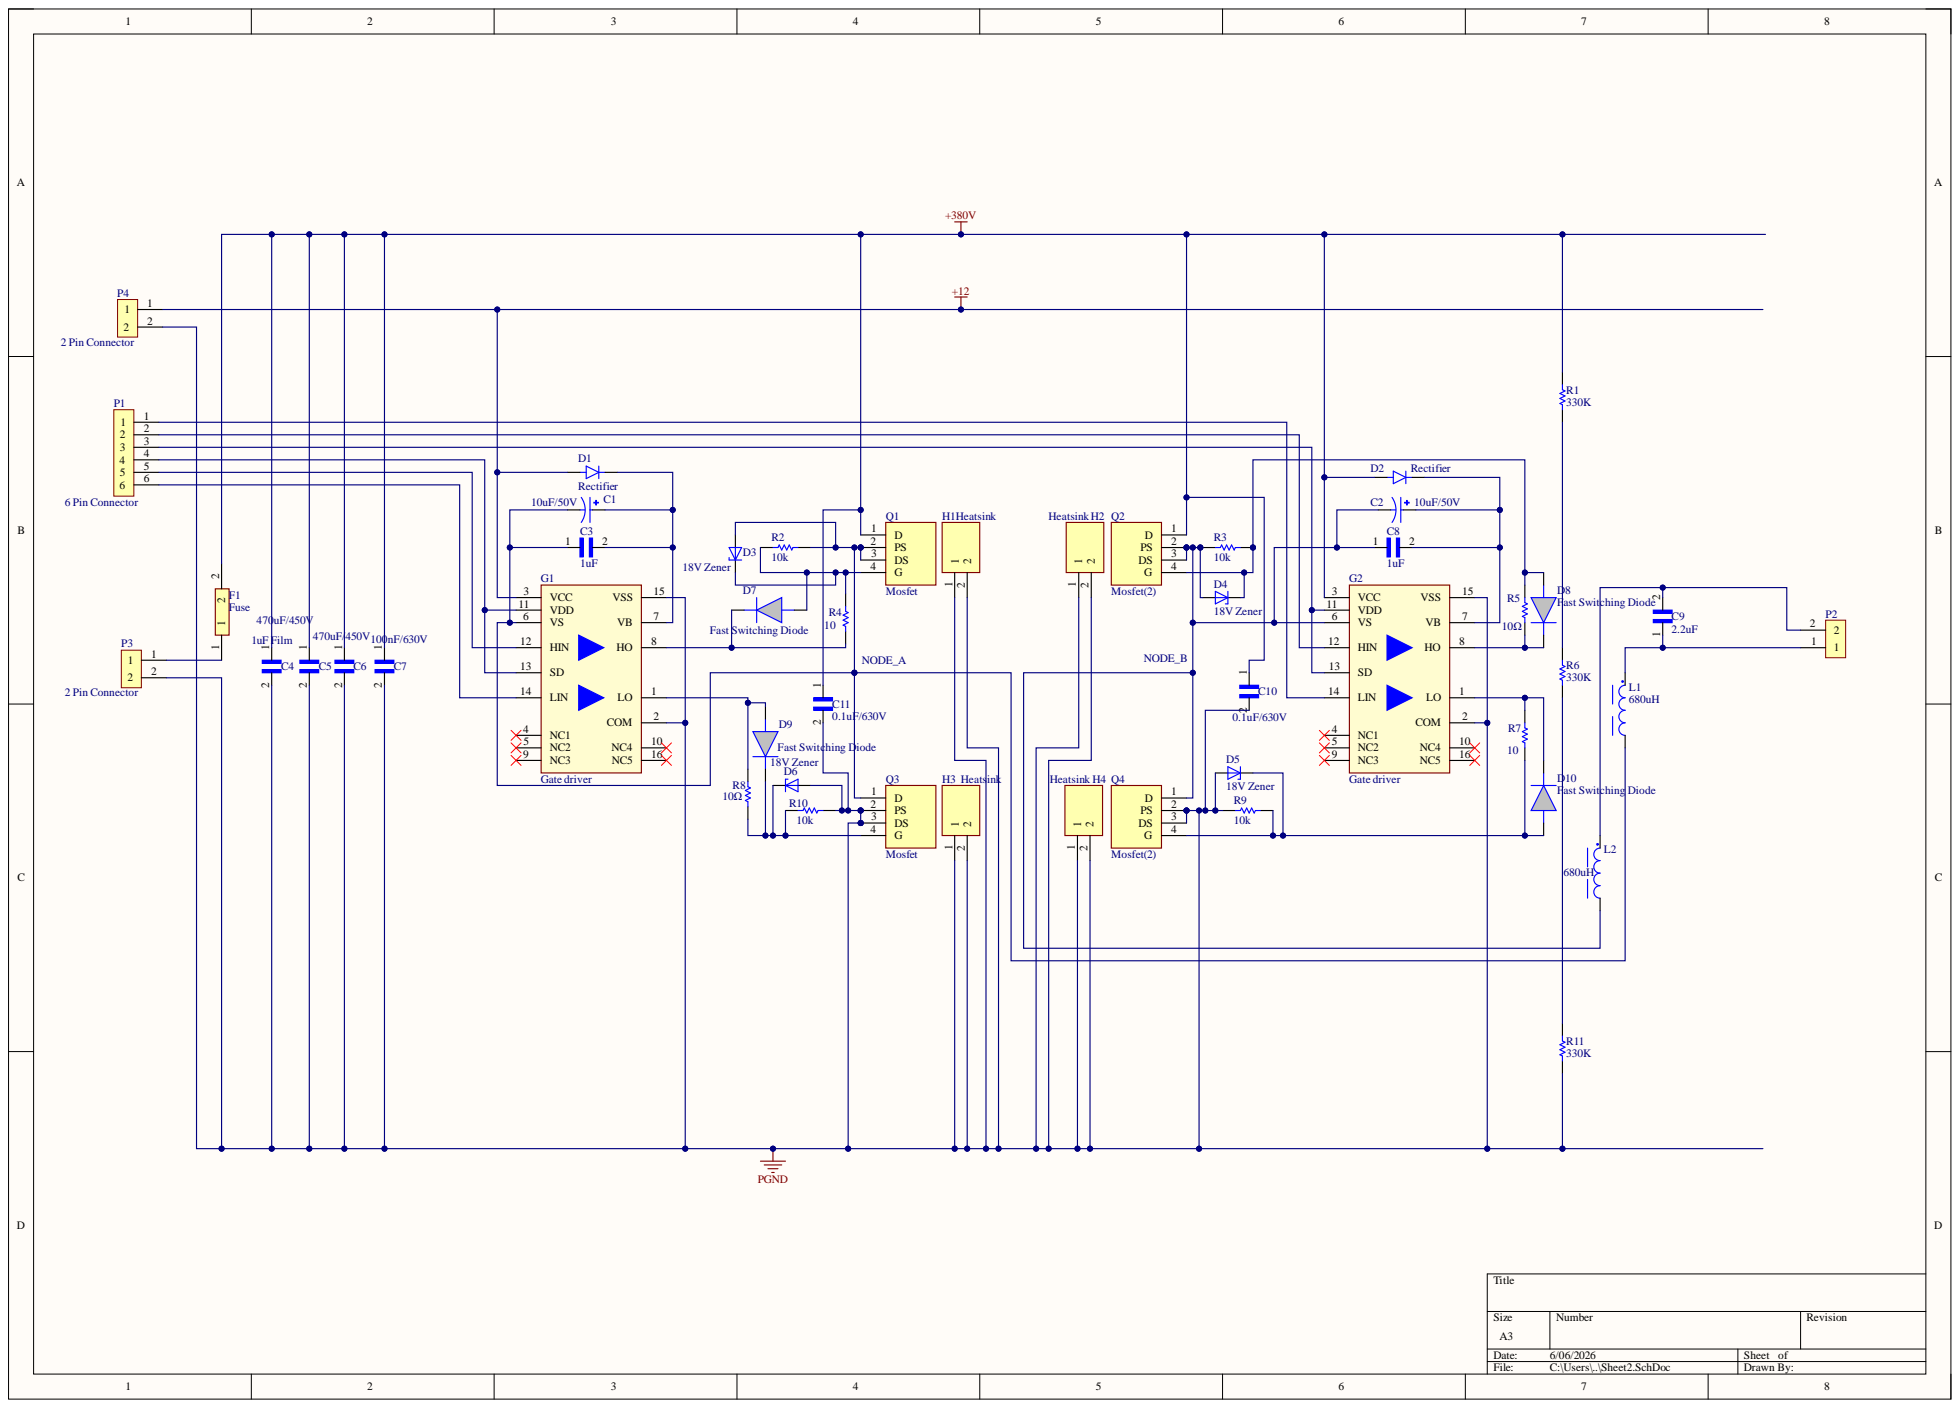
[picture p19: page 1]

4 | D 1 | Q H 1 Heat s i nk Heat s i nk H 2 Q

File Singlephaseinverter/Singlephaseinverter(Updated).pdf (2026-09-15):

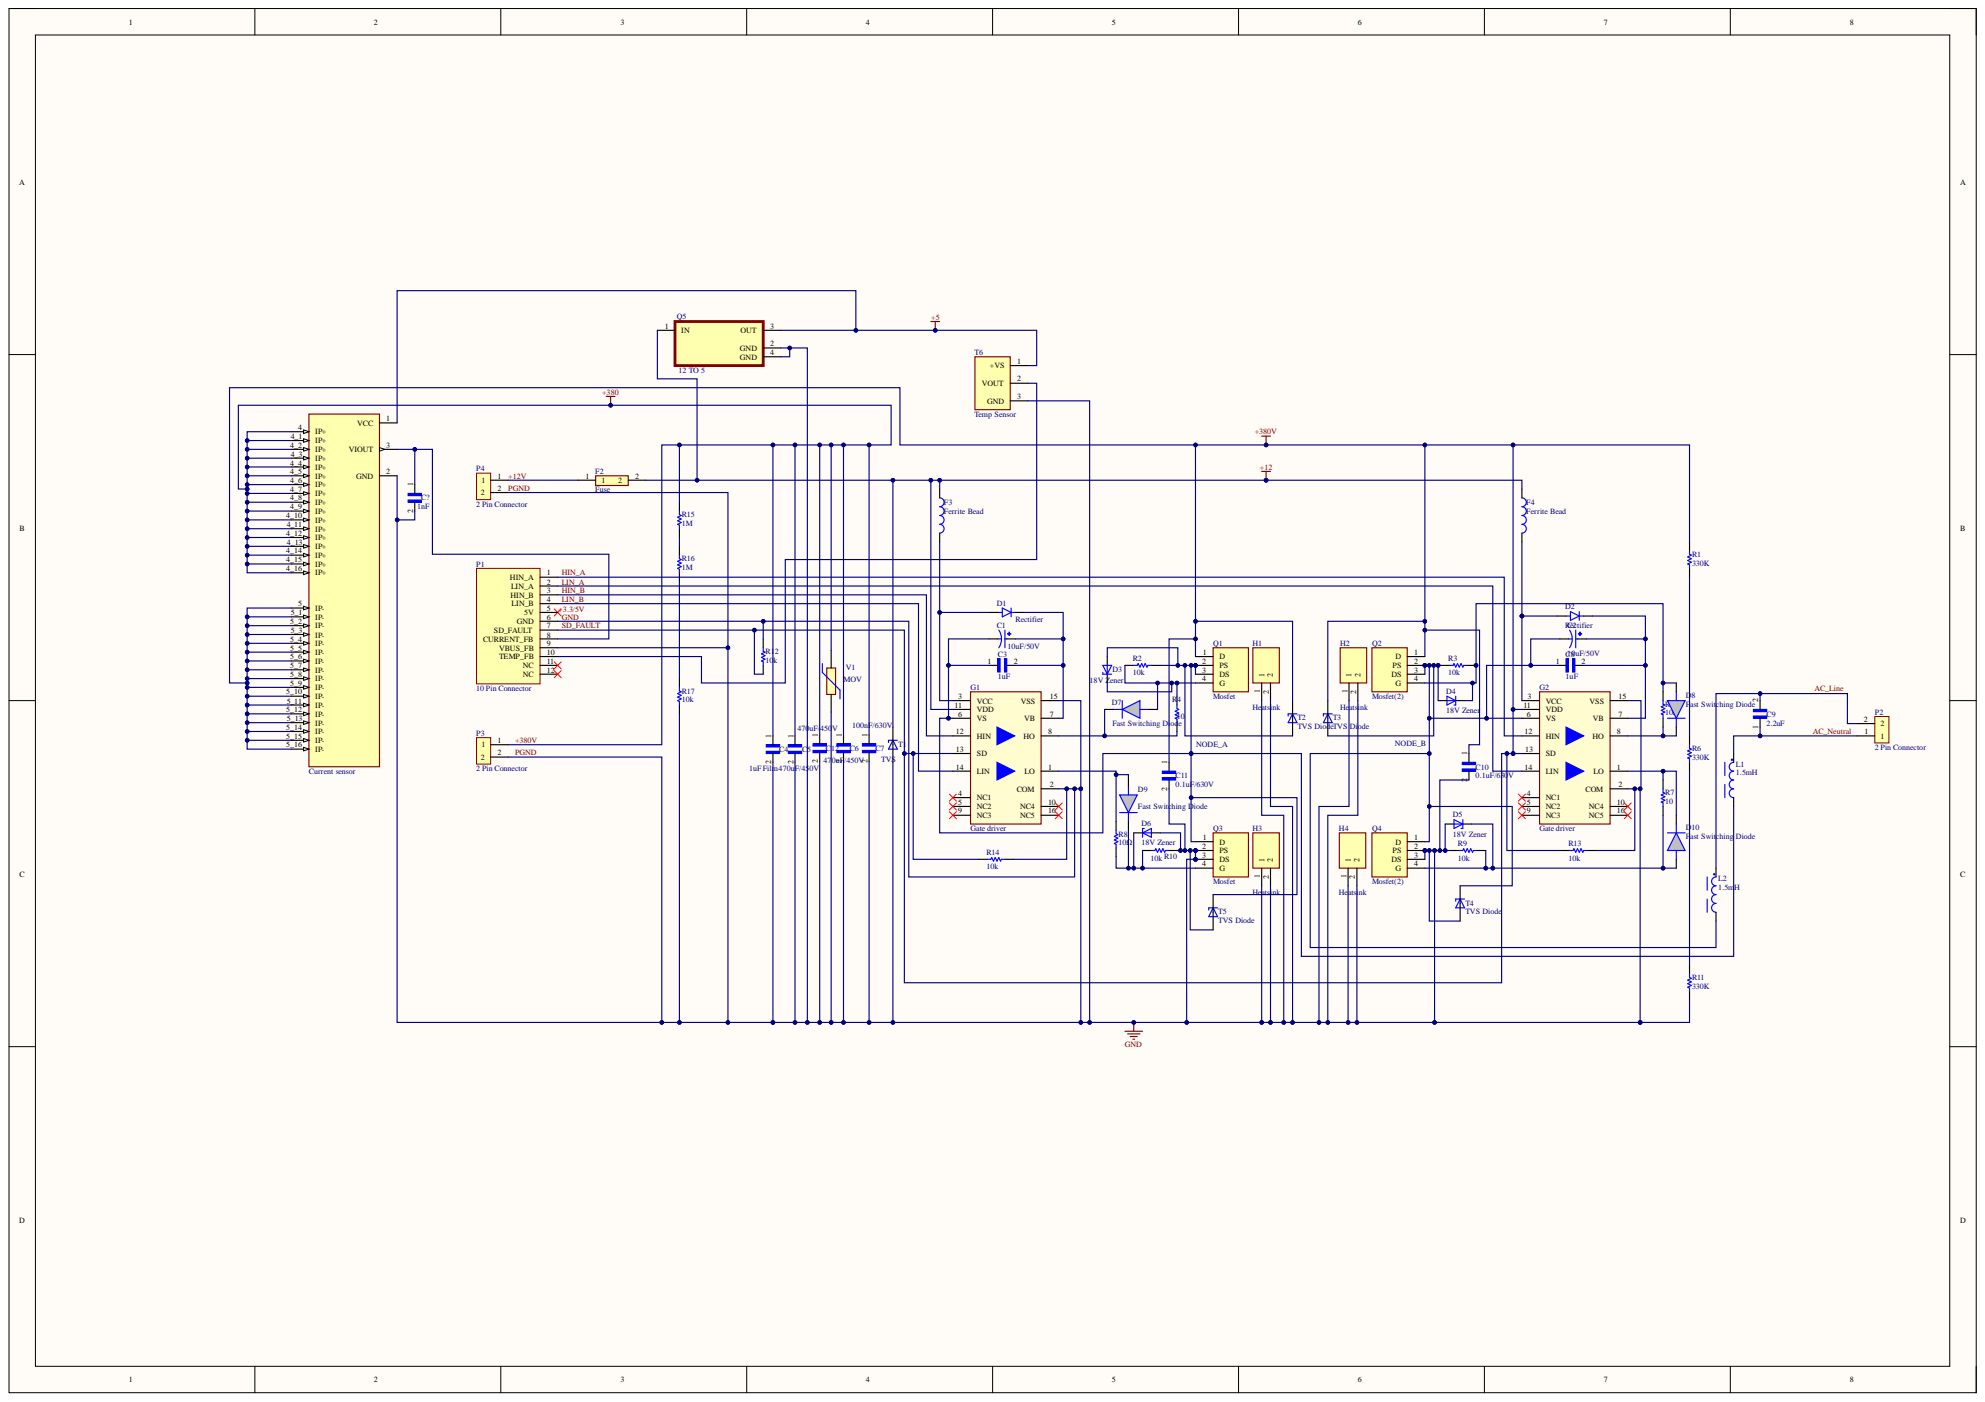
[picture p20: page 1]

2 | T 6

VC C I IP+ 4_2 IP+ 4_3 IP+ 4_4 IP+ 4_5 IP+ 4_6 IP+ 4_7 IP+ 4_8 IP+ 4_9 IP+ 4_10 IP+ 4_11 IP+ 4_12 IP+ 4_13 IP+ 4_14 IP+ 4_15 IP+ 4_16 IP- 5 IP- 5_1 IP- 5_2 IP- 5_3 IP- 5_4 IP- 5_5 IP- 5_6 IP- 5_7 IP- 5_8 IP- 5_9 IP- 5_10 IP- 5_11 IP- 5_12 IP- 5_13 IP- 5_14 IP- 5_15 IP- 5_16 P+ P+ 4_1 I VIOUT GND | Temp S ensor

1 2 | 2 | 1 2 Fus e | F 3 F e | r rite B e a d

5 | +3.3/5 V GND SD_FAULT | 1MR17

3 | HIN_B LIN_B | | D1

3 | 3 | 10k

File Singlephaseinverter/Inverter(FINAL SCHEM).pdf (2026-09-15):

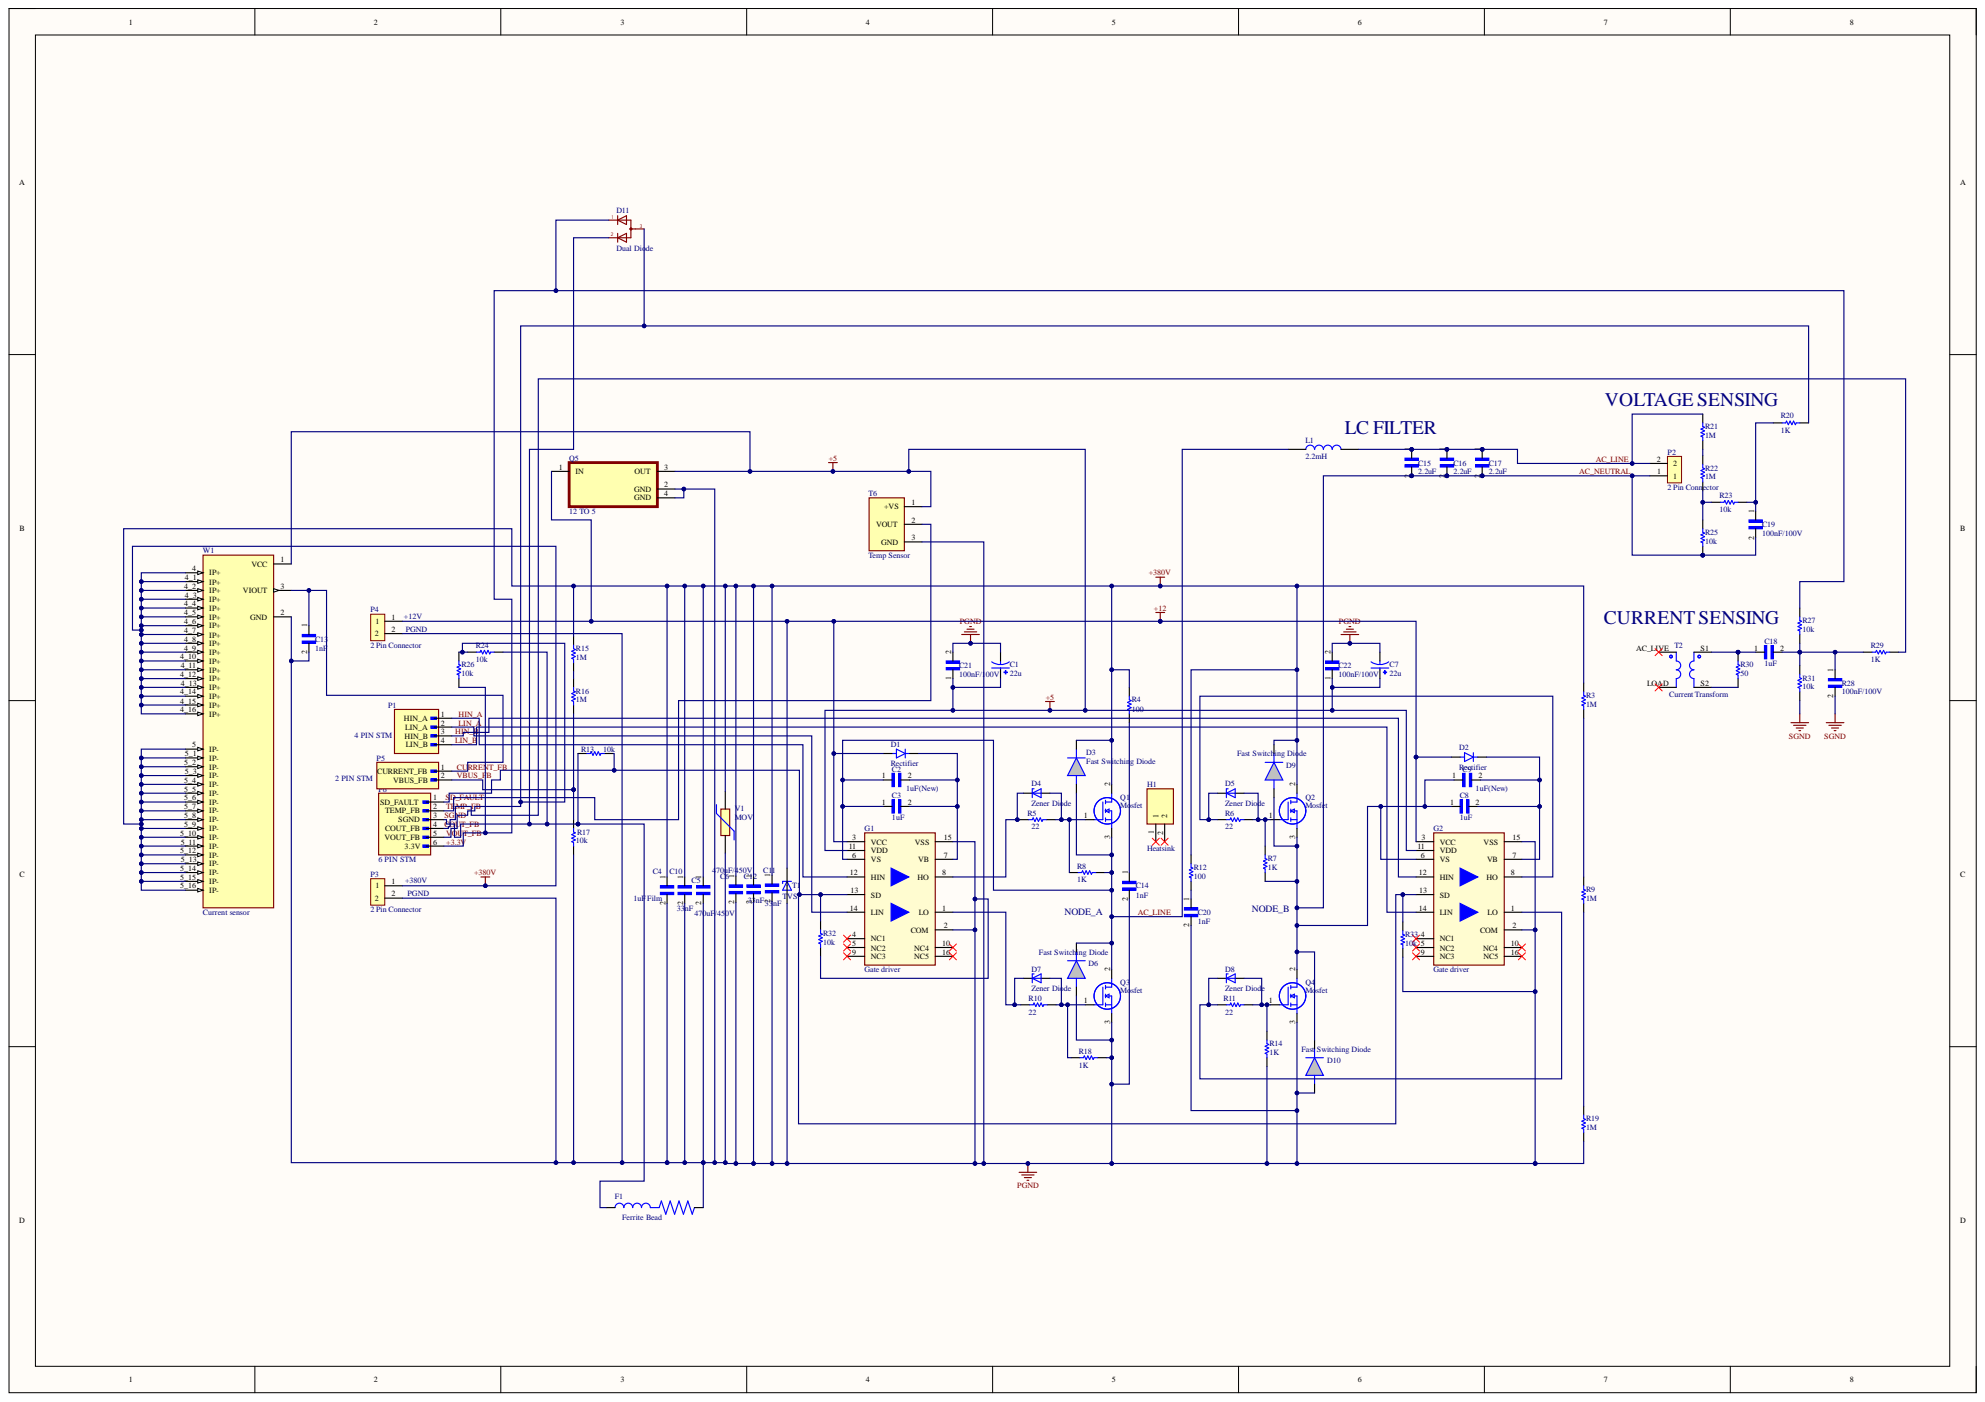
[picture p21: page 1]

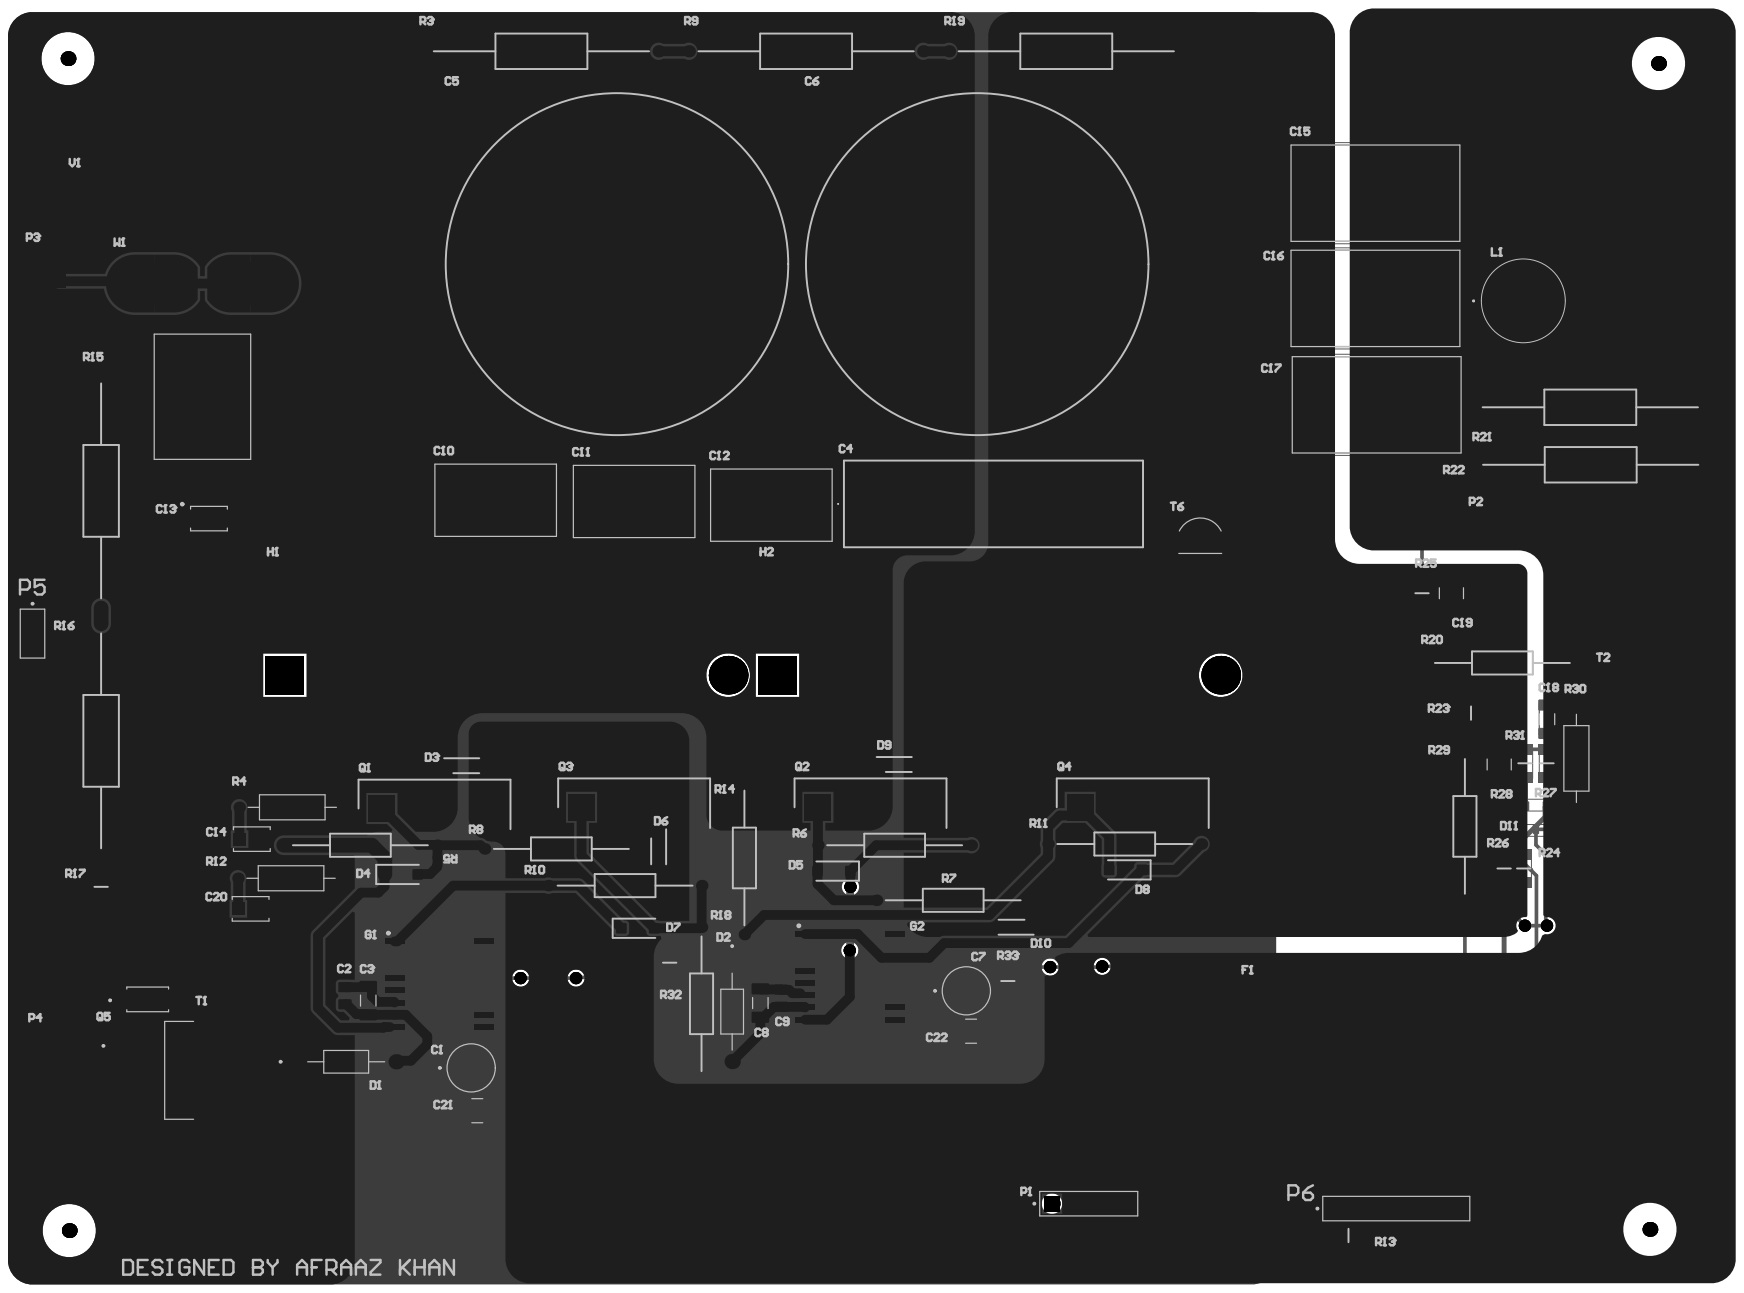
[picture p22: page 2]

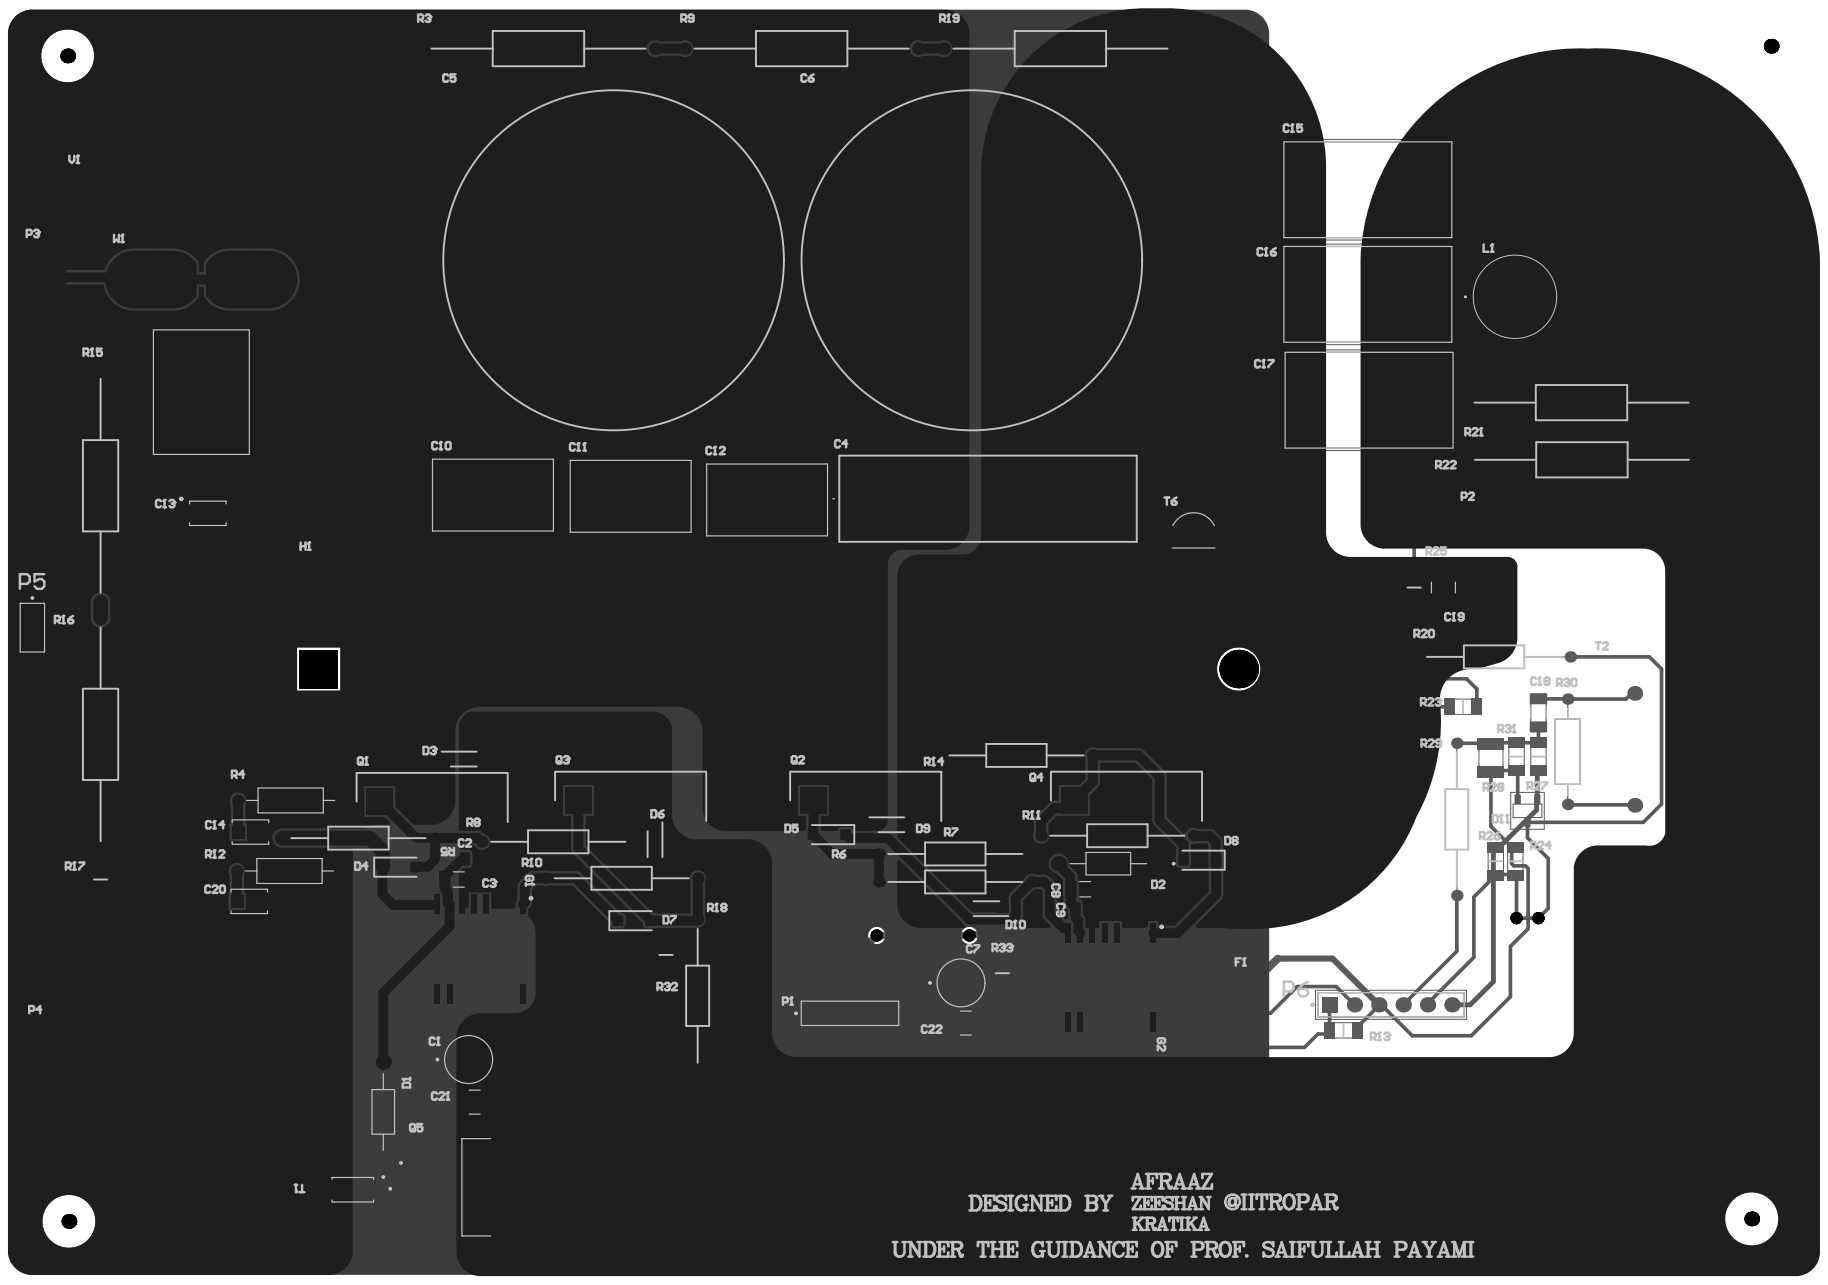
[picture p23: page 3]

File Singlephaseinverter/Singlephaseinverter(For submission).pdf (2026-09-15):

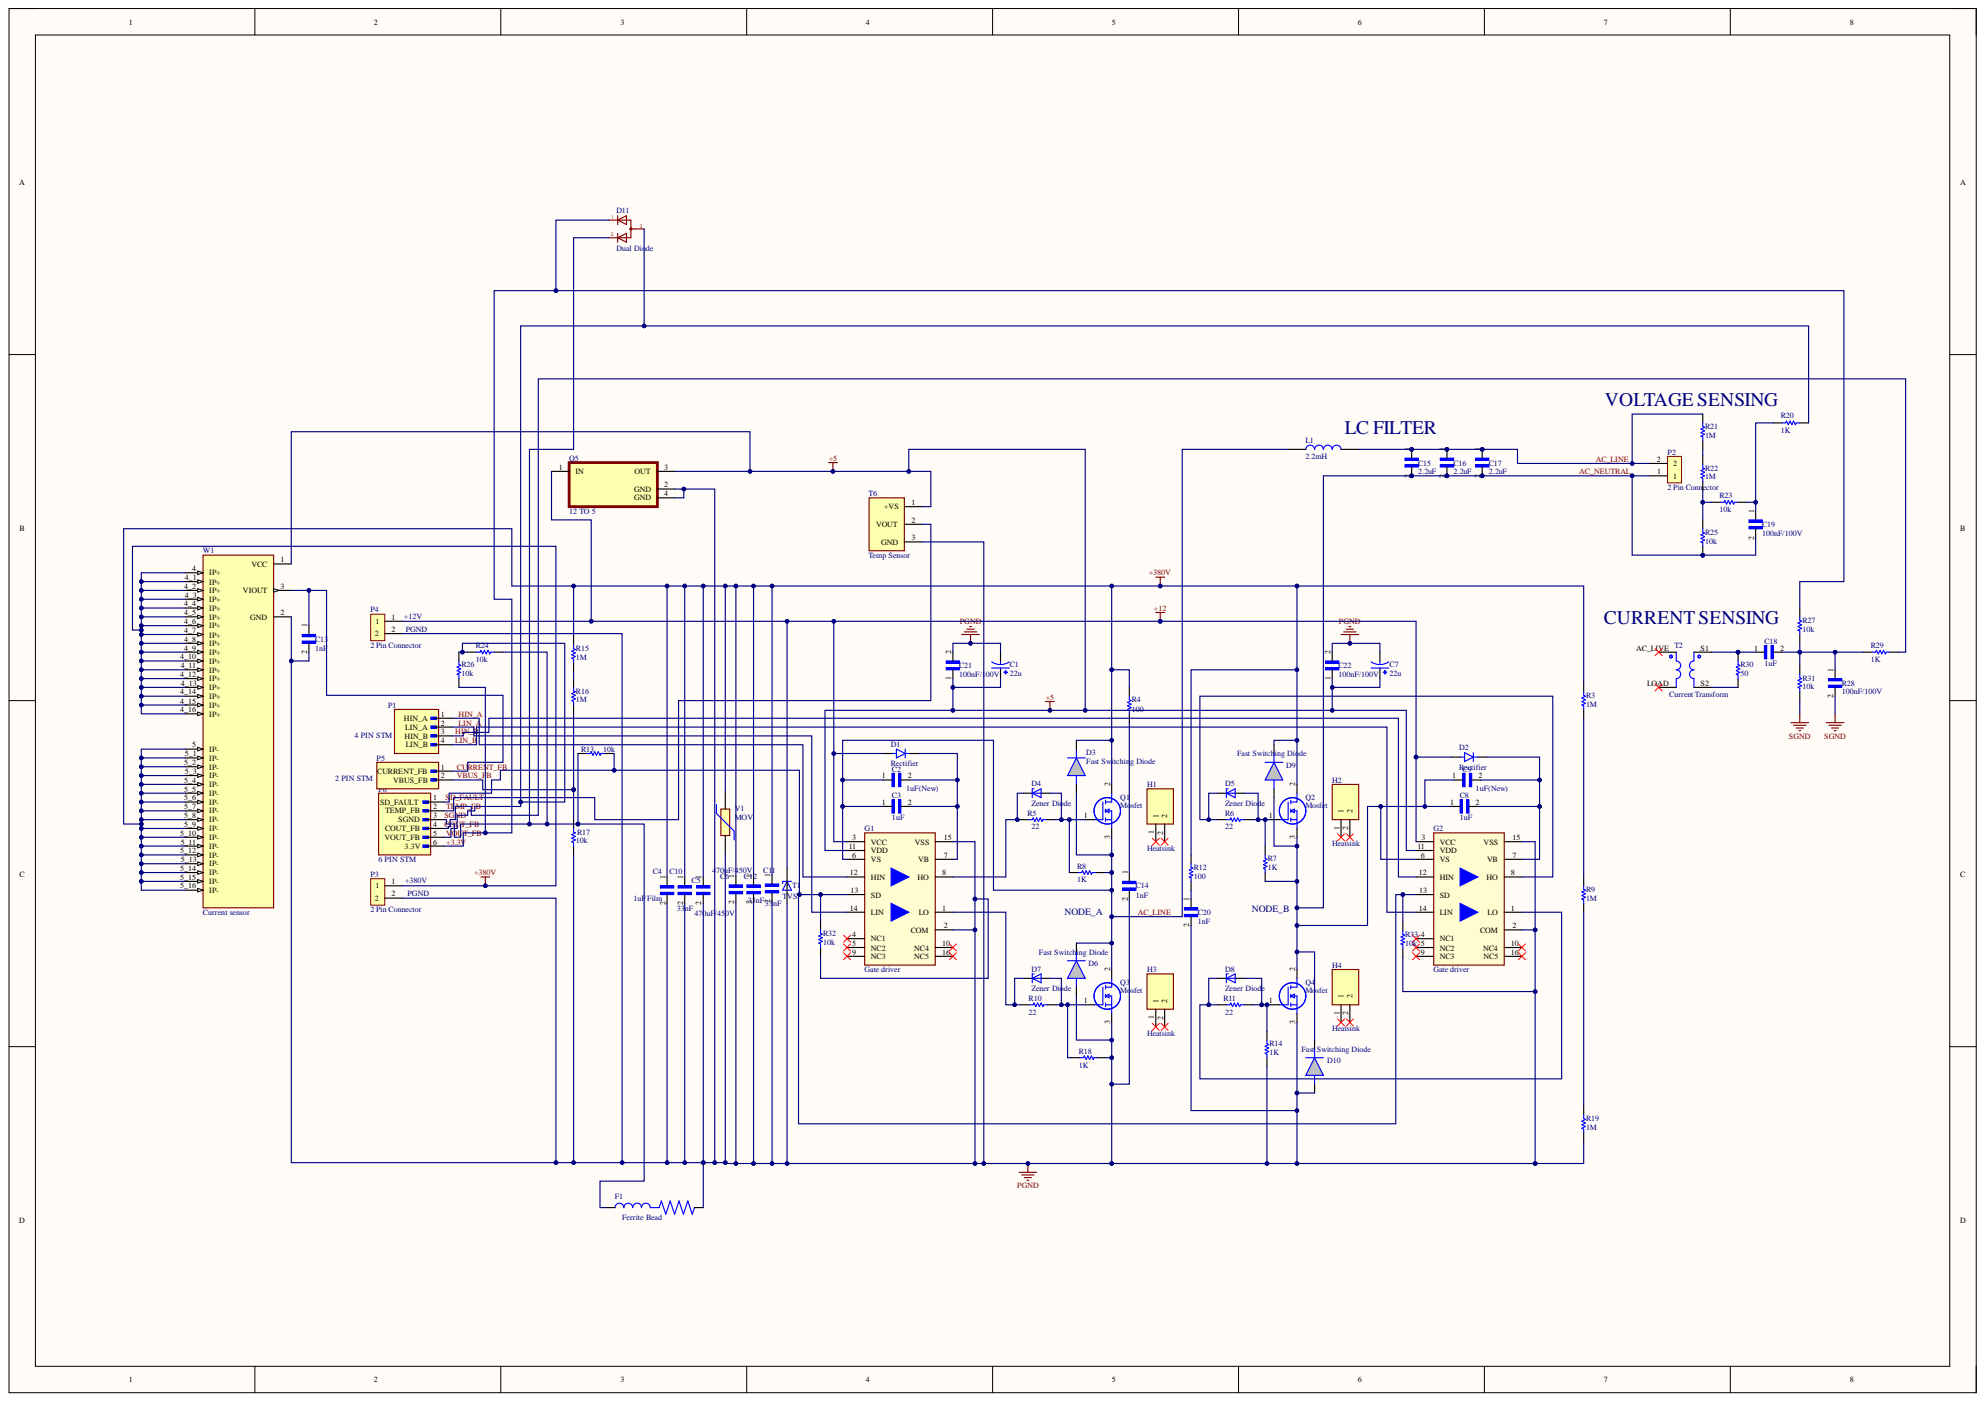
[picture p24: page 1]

4 HIN_B 3 LIN_A 2 HIN_A 1

HIN_B LIN_B | H1 C14
